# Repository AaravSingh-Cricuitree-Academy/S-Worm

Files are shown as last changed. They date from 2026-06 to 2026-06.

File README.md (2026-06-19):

# S-Worm
_Swarm based Watch operations for rescue missions_

Untitled design (16)

## Basic architechtural overview-
Essentially its a system of 2 different types of drones
1) The recon
2) The rescuer
   
And also

-> Ground station

Recon drone
-> The ground station uses TDMA architechture to direct ALL the drones.

-> This is intended to be used in situations of disaster like earthquakes, tsunamis, bombings ,and/or mapping out complex terrain. 

Both share the same flight controller and ESC board. The difference in them is speciality boards which are unique to the respective drone, defined below-

-> The recon's speciality board is equiped with a Camera and LIDAR which hovers over terrain to map it out and then stores it. After a full map out it sends the data to the ground station where the data is processed and the area is divided into zones and high risk areas.

-> The rescue is equipped with a Mic, GPR to, Thermal and regular camera all processed by a PI hat 2 to look for human signals even under debris.

Add a heading (1)

_Check [Hardware ReadMe](Hardware/Hardware_ReadMe.md) to have an in-depth
 overview of exactly what has been built ;)_

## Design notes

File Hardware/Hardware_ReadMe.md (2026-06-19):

# HARDWARE SPECS-



**Processing & Control**

    1 STM32F405RGT6 (Main Flight Controller MCU)- Brain of the system
    
    2 ADS112U04IPWR (Precision ADC)
  
**Navigation & Positioning**

    1) MAX-M10S-00B (GNSS/GPS Module) + U.FL connector
    
    2) BMP580 (Barometric Pressure Sensor)
    
    3) ICM-45686 (6-axis IMU)
    
    4) MMC5983MA (3-axis Magnetometer)
  
**Communications**

		1) E22-900M22S (900 MHz Telemetry/Radio Module) + U.Fl connector
		
**Power System**

	1) TPS2121RUXR (Power Multiplexer / Power Path Controller)
	2) TPS62130RGTR (Buck Converter)
	3) 2.2 µH Power Inductor
	
**Clock Sources**

	1) X322525MOB4SI- 25 MHz Crystal Oscillator
	2) Q13FC1350000400- 32.768 kHz Crystal (LSE)

**User Interface & Debug**

	1) USB-A Connector
	2) 3 × Status LEDs
	3) 2 × Tactile Push Buttons for reset and boot
	4) Test pads for major nets

**Passive Components**

	Decoupling capacitors (100 nF, 1 µF, 2.2 µF, 4.7 µF, 10 µF, 22 µF)
	Timing/load capacitors (6.8 pF, 20 pF)
	Filtering capacitors (3.3 nF, 10 nF)
	Resistor network (10 kΩ, 30 kΩ, 75 kΩ, 80 kΩ, 100 kΩ)
	FCM1608KF-601T03 (Ferrite Bead)

## Build reasoning
STM32F405 because i was drawing inspo from the existing speedybee f405 board

I ran out of ADCs in my STM32 so im reading the voltage given by my battery via a voltage divider and ADC to convert the analog voltage to UART so my STM32 can read it.

Cloclks, buttons, IMU, magnetometer and barometeric sensor were picked up from the guide

Power mux to allow seamless switch between USB power and battery power. 

E22-900M-2S because it has long range and I have worked with the module before

MAX-M10S-00B good features at a reasonable cost

Passive compnents were selected from the datasheet and/or the guide

Rest is rather self explainatory

## Schematic for quick reference



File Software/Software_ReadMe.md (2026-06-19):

# Software 
Yeah so this is just STM32cubeMX generated code nothing much to see here

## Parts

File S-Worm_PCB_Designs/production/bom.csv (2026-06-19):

Designator | Footprint | Quantity | Value | LCSC Part #
C10, C11, C12, C15, C20, C22, C26, C27, C32, C5, C6, C7 | 0402 | 12 | 100nF
C13, C9 | 0402 | 2 | 6.8pF
C14, C8 | 0402 | 2 | 20pF
C16 | 0402 | 1 | 1uF
C17, C18 | 0402 | 2 | 2.2uF
C19 | 0805 | 1 | 10uF
C2, C4 | 0402 | 2 | 4.7uF
C21, C30 | 0402 | 2 | 10uF
C23, C25, C31, C33 | 0402 | 4 | 0.1uF
C24 | 0402 | 1 | 3.3nF
C28 | 0402 | 1 | 10nF
C29 | 0402 | 1 | 22uf
D1, D2, D3 | 0805 | 3 | LED
J1 | USB_A_CNCTech_1001-011-01101_Horizontal | 1 | USB_A
J2, J3 | U.FL_Hirose_U.FL-R-SMT-1_Vertical | 2 | Conn_Coaxial
J4 | JST_ACH_BM03B-ACHSS-GAN-ETF_1x03-1MP_P1.20mm_Vertical | 1 | Conn_01x03_Pin
L1 | L0603 | 1 | FCM1608KF-601T03 | C141723
L2 | 0201 | 1 | 2.2 uH
R1, R2 | 0201 | 2 | 10k
R3 | 0402 | 1 | 75k
R4 | 0402 | 1 | 80k
R5 | 0402 | 1 | 30k
R6 | 0402 | 1 | 10k
R7, R8 | 0402 | 2 | 100k
SW1, SW2 | SW-SMD_L3.9-W3.0-P4.45 | 2 | TS-1088-AR02016 | C720477
TP1 | TestPoint_Pad_4.0x4.0mm | 1 | SP-_4
TP10 | TestPoint_Pad_4.0x4.0mm | 1 | 3.3v test pad
TP11 | TestPoint_Pad_4.0x4.0mm | 1 | GND test pad
TP2 | TestPoint_Pad_4.0x4.0mm | 1 | SP-_2
TP3 | TestPoint_Pad_4.0x4.0mm | 1 | SP-_3
TP4 | TestPoint_Pad_4.0x4.0mm | 1 | SP-_1
TP5 | TestPoint_Pad_4.0x4.0mm | 1 | SP+_4
TP6 | TestPoint_Pad_4.0x4.0mm | 1 | SP+_1
TP7 | TestPoint_Pad_4.0x4.0mm | 1 | SP+_3
TP8 | TestPoint_Pad_4.0x4.0mm | 1 | SP+_2
TP9 | TestPoint_Pad_4.0x4.0mm | 1 | Battery test pad
U1 | SMD-18_L10.1-W9.7-P1.10-TL_SKG09F | 1 | MAX-M10S-00B | C4153167
U2 | LQFP-64_L10.0-W10.0-P0.50-LS12.0-BL | 1 | STM32F405RGT6 | C15742
U3 | LGA-14_L3.0-W2.5-P0.50-TL | 1 | ICM-45686 | C22459454
U4 | LGA-16_L3.0-W3.0-P0.50-BL_SQ | 1 | MMC5983MA | C404329
U5 | VQFN-HR-12_L2.5-W2.0-P0.50-BL | 1 | TPS2121RUXR | C485916
U6 | QFN-16_L3.0-W3.0-P0.50-TL-EP1.7 | 1 | TPS62130RGTR | C43590
U7 | WIRELM-SMD_E22-900M22S | 1 | E22-900M22S | C411293
U8 | LGA-10_L2.0-W2.0-P0.50-TL_BMP580 | 1 | BMP580 | C22391138
U9 | TSSOP-16_L5.0-W4.4-P0.65-LS6.4-BL | 1 | ADS112U04IPWR | C701616
X1 | CRYSTAL-SMD_4P-L3.2-W2.5-BL | 1 | X322525MOB4SI | C9006
X2 | FC-135R_L3.2-W1.5 | 1 | Q13FC1350000400 | C32346

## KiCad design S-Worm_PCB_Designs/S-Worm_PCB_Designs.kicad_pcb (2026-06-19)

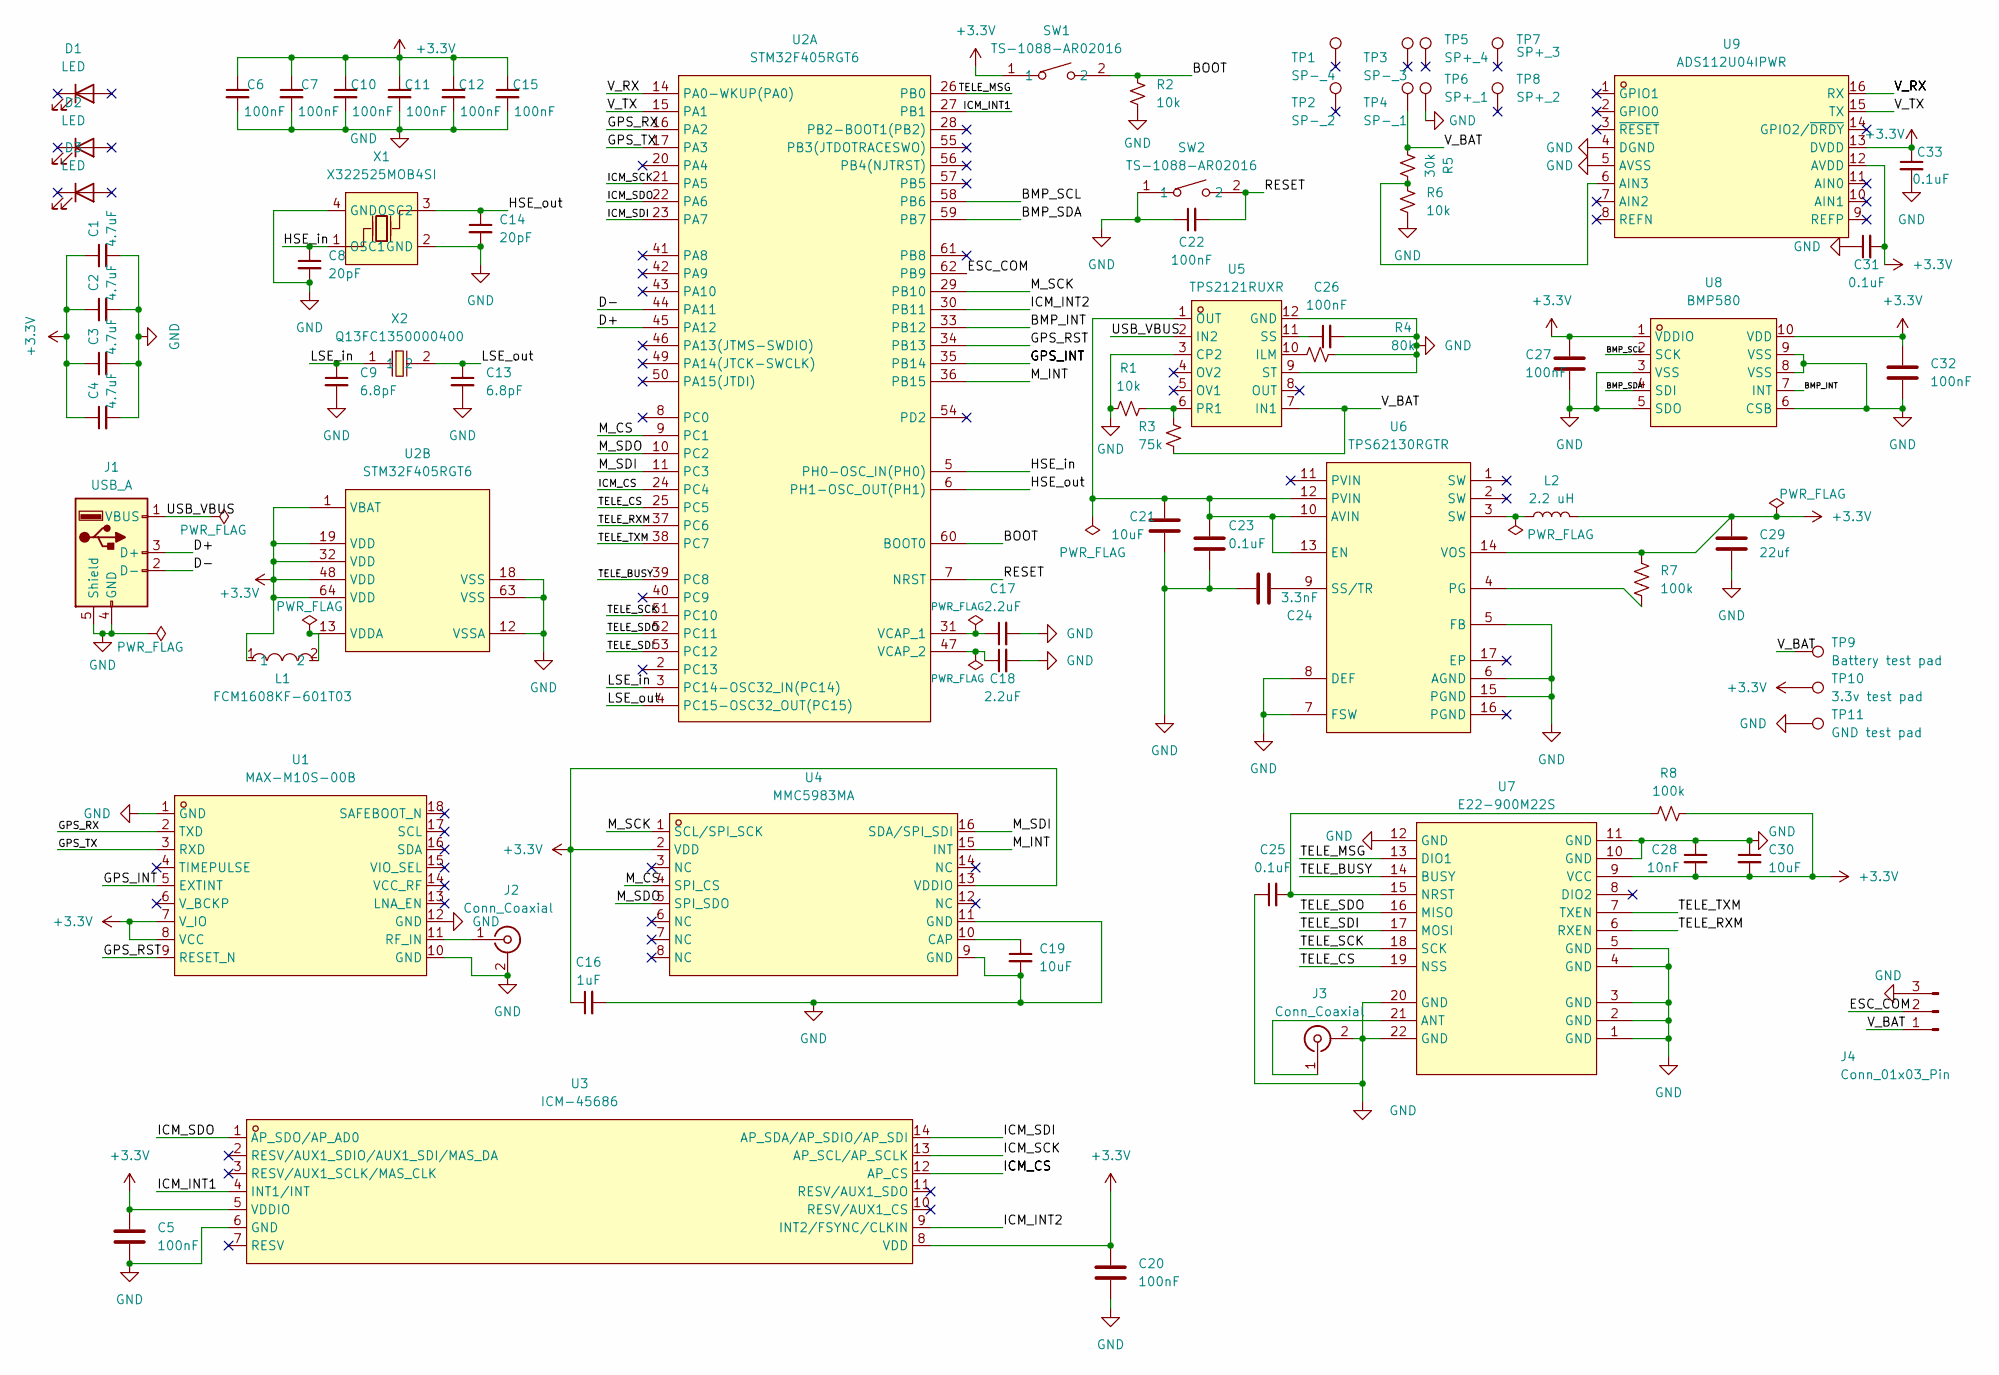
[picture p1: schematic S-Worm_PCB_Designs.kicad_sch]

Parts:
C1, C2, C3, C4: 4.7uF; C_0402_1005Metric
C5, C6, C7, C10, C11, C12, C15, C20, C22, C26, C27, C32: 100nF; C_0402_1005Metric
C8, C14: 20pF; C_0402_1005Metric
C9, C13: 6.8pF; C_0402_1005Metric
C16: 1uF; C_0402_1005Metric
C17, C18: 2.2uF; C_0402_1005Metric
C19: 10uF; C_0805_2012Metric
C21, C30: 10uF; C_0402_1005Metric
C23, C25, C31, C33: 0.1uF; C_0402_1005Metric
C24: 3.3nF; C_0402_1005Metric
C28: 10nF; C_0402_1005Metric
C29: 22uf; C_0402_1005Metric
D1, D2, D3: LED; LED_0805_2012Metric
J1: USB_A; USB_A_CNCTech_1001-011-01101_Horizontal
J2, J3: Conn_Coaxial; U.FL_Hirose_U.FL-R-SMT-1_Vertical
J4: Conn_01x03_Pin; JST_ACH_BM03B-ACHSS-GAN-ETF_1x03-1MP_P1.20mm_Vertical
L1: FCM1608KF-601T03; L0603; MPN FCM1608KF-601T03; LCSC Part C141723
L2: 2.2 uH; L_0201_0603Metric
R1, R2: 10k; R_0201_0603Metric
R3: 75k; R_0402_1005Metric
R4: 80k; R_0402_1005Metric
R5: 30k; R_0402_1005Metric
R6: 10k; R_0402_1005Metric
R7, R8: 100k; R_0402_1005Metric
SW1, SW2: TS-1088-AR02016; SW-SMD_L3.9-W3.0-P4.45; MPN TS-1088-AR02016; LCSC Part C720477
TP1: SP-_4; TestPoint_Pad_4.0x4.0mm
TP2: SP-_2; TestPoint_Pad_4.0x4.0mm
TP3: SP-_3; TestPoint_Pad_4.0x4.0mm
TP4: SP-_1; TestPoint_Pad_4.0x4.0mm
TP5: SP+_4; TestPoint_Pad_4.0x4.0mm
TP6: SP+_1; TestPoint_Pad_4.0x4.0mm
TP7: SP+_3; TestPoint_Pad_4.0x4.0mm
TP8: SP+_2; TestPoint_Pad_4.0x4.0mm
TP9: Battery test pad; TestPoint_Pad_4.0x4.0mm
TP10: 3.3v test pad; TestPoint_Pad_4.0x4.0mm
TP11: GND test pad; TestPoint_Pad_4.0x4.0mm
U1: MAX-M10S-00B; SMD-18_L10.1-W9.7-P1.10-TL_SKG09F; MPN MAX-M10S-00B; LCSC Part C4153167
U2: STM32F405RGT6; LQFP-64_L10.0-W10.0-P0.50-LS12.0-BL; MPN STM32F405RGT6; LCSC Part C15742
U3: ICM-45686; LGA-14_L3.0-W2.5-P0.50-TL; MPN ICM-45686; LCSC Part C22459454
U4: MMC5983MA; LGA-16_L3.0-W3.0-P0.50-BL_SQ; MPN MMC5983MA; LCSC Part C404329
U5: TPS2121RUXR; VQFN-HR-12_L2.5-W2.0-P0.50-BL; MPN TPS2121RUXR; LCSC Part C485916
U6: TPS62130RGTR; QFN-16_L3.0-W3.0-P0.50-TL-EP1.7; MPN TPS62130RGTR; LCSC Part C43590
U7: E22-900M22S; WIRELM-SMD_E22-900M22S; MPN E22-900M22S; LCSC Part C411293
U8: BMP580; LGA-10_L2.0-W2.0-P0.50-TL_BMP580; MPN BMP580; LCSC Part C22391138
U9: ADS112U04IPWR; TSSOP-16_L5.0-W4.4-P0.65-LS6.4-BL; MPN ADS112U04IPWR; LCSC Part C701616
X1: X322525MOB4SI; CRYSTAL-SMD_4P-L3.2-W2.5-BL; MPN X322525MOB4SI; LCSC Part C9006
X2: Q13FC1350000400; FC-135R_L3.2-W1.5; MPN Q13FC13500004; LCSC Part C32346

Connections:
+3.3V: C1.1, C2.1, C3.1, C4.1, C5.1, C6.1, C7.1, C10.1, C11.1, C12.1, C15.1, C16.1, C20.1, C27.1, C28.2, C29.1, C30.2, C31.2, C32.1, C33.1, L1.1, L2.2, R7.1, R8.2, SW1.1, TP10.1, U1.7 (V_IO), U1.8 (VCC), U2.1 (VBAT), U2.19 (VDD), U2.32 (VDD), U2.48 (VDD), U2.64 (VDD), U3.5 (VDDIO), U3.8 (VDD), U4.2 (VDD), U4.13 (VDDIO), U6.14 (VOS), U7.9 (VCC), U8.1 (VDDIO), U8.10 (VDD), U9.12 (AVDD), U9.13 (DVDD)
/BMP_INT: U2.33 (PB12), U8.7 (INT)
/BMP_SCL: U2.58 (PB6), U8.2 (SCK)
/BMP_SDA: U2.59 (PB7), U8.4 (SDI)
/BOOT: R2.1, SW1.2, U2.60 (BOOT0)
/D+: J1.3 (D+), U2.45 (PA12)
/D-: J1.2 (D-), U2.44 (PA11)
/ESC_COM: J4.2, U2.62 (PB9)
/GPS_INT: U1.5 (EXTINT), U2.35 (PB14)
/GPS_RST: U1.9 (RESET_N), U2.34 (PB13)
/GPS_RX: U1.2 (TXD), U2.16 (PA2)
/GPS_TX: U1.3 (RXD), U2.17 (PA3)
/HSE_in: C8.1, U2.5 (PH0-OSC_IN(PH0)), X1.1 (OSC1)
/HSE_out: C14.1, U2.6 (PH1-OSC_OUT(PH1)), X1.3 (OSC2)
/ICM_CS: U2.24 (PC4), U3.12 (AP_CS)
/ICM_INT1: U2.27 (PB1), U3.4 (INT1/INT)
/ICM_INT2: U2.30 (PB11), U3.9 (INT2/FSYNC/CLKIN)
/ICM_SCK: U2.21 (PA5), U3.13 (AP_SCL/AP_SCLK)
/ICM_SDI: U2.23 (PA7), U3.14 (AP_SDA/AP_SDIO/AP_SDI)
/ICM_SDO: U2.22 (PA6), U3.1 (AP_SDO/AP_AD0)
/LSE_in: C9.1, U2.3 (PC14-OSC32_IN(PC14)), X2.1
/LSE_out: C13.1, U2.4 (PC15-OSC32_OUT(PC15)), X2.2
/M_CS: U2.9 (PC1), U4.4 (SPI_CS)
/M_INT: U2.36 (PB15), U4.15 (INT)
/M_SCK: U2.29 (PB10), U4.1 (SCL/SPI_SCK)
/M_SDI: U2.11 (PC3), U4.16 (SDA/SPI_SDI)
/M_SDO: U2.10 (PC2), U4.5 (SPI_SDO)
/RESET: C22.2, SW2.2, U2.7 (NRST)
/TELE_BUSY: U2.39 (PC8), U7.14 (BUSY)
/TELE_CS: U2.25 (PC5), U7.19 (NSS)
/TELE_MSG: U2.26 (PB0), U7.13 (DIO1)
/TELE_RXM: U2.37 (PC6), U7.6 (RXEN)
/TELE_SCK: U2.51 (PC10), U7.18 (SCK)
/TELE_SDI: U2.53 (PC12), U7.17 (MOSI)
/TELE_SDO: U2.52 (PC11), U7.16 (MISO)
/TELE_TXM: U2.38 (PC7), U7.7 (TXEN)
/USB_VBUS: J1.1 (VBUS), U5.2 (IN2)
/V_BAT: J4.1, R3.2, R5.1, TP4.1, TP9.1, U5.7 (IN1)
/V_RX: U2.14 (PA0-WKUP(PA0)), U9.16 (RX)
/V_TX: U2.15 (PA1), U9.15 (TX)
GND: C1.2, C2.2, C3.2, C4.2, C5.2, C6.2, C7.2, C8.2, C9.2, C10.2, C11.2, C12.2, C13.2, C14.2, C15.2, C16.2, C17.2, C18.2, C19.2, C20.2, C21.2, C22.1, C23.2, C24.2, C25.1, C26.2, C27.2, C28.1, C29.2, C30.1, C31.1, C32.2, C33.2, J1.4 (GND), J1.5 (Shield), J2.2 (Ext), J3.2 (Ext), J4.3, J4.MP, R1.1, R2.2, R4.2, R6.2, SW2.1, TP6.1, TP11.1, U1.1 (GND), U1.10 (GND), U1.12 (GND), U2.12 (VSSA), U2.18 (VSS), U2.63 (VSS), U3.6 (GND), U4.9 (GND), U4.11 (GND), U5.3 (CP2), U5.9 (ST), U5.12 (GND), U6.5 (FB), U6.6 (AGND), U6.7 (FSW), U6.8 (DEF), U6.15 (PGND), U7.1 (GND), U7.2 (GND), U7.3 (GND), U7.4 (GND), U7.5 (GND), U7.10 (GND), U7.11 (GND), U7.12 (GND), U7.20 (GND), U7.22 (GND), U8.3 (VSS), U8.5 (SDO), U8.6 (CSB), U8.8 (VSS), U8.9 (VSS), U9.4 (DGND), U9.5 (AVSS), X1.2 (GND), X1.4 (GND)
unnamed: J2.1 (In), U1.11 (RF_IN)
unnamed: J3.1 (In), U7.21 (ANT)
unnamed: L2.1, U6.3 (SW)
unnamed: C17.1, U2.31 (VCAP_1)
unnamed: C18.1, U2.47 (VCAP_2)
unnamed: L1.2, U2.13 (VDDA)
unnamed: C19.1, U4.10 (CAP)
unnamed: R4.1, U5.10 (ILM)
unnamed: R1.2, R3.1, U5.6 (PR1)
unnamed: C26.1, U5.11 (SS)
unnamed: C21.1, C23.1, U5.1 (OUT), U6.10 (AVIN), U6.12 (PVIN), U6.13 (EN)
unnamed: R7.2, U6.4 (PG)
unnamed: C24.1, U6.9 (SS/TR)
unnamed: C25.2, R8.1, U7.15 (NRST)
unnamed: R5.2, R6.1, U9.6 (AIN3)

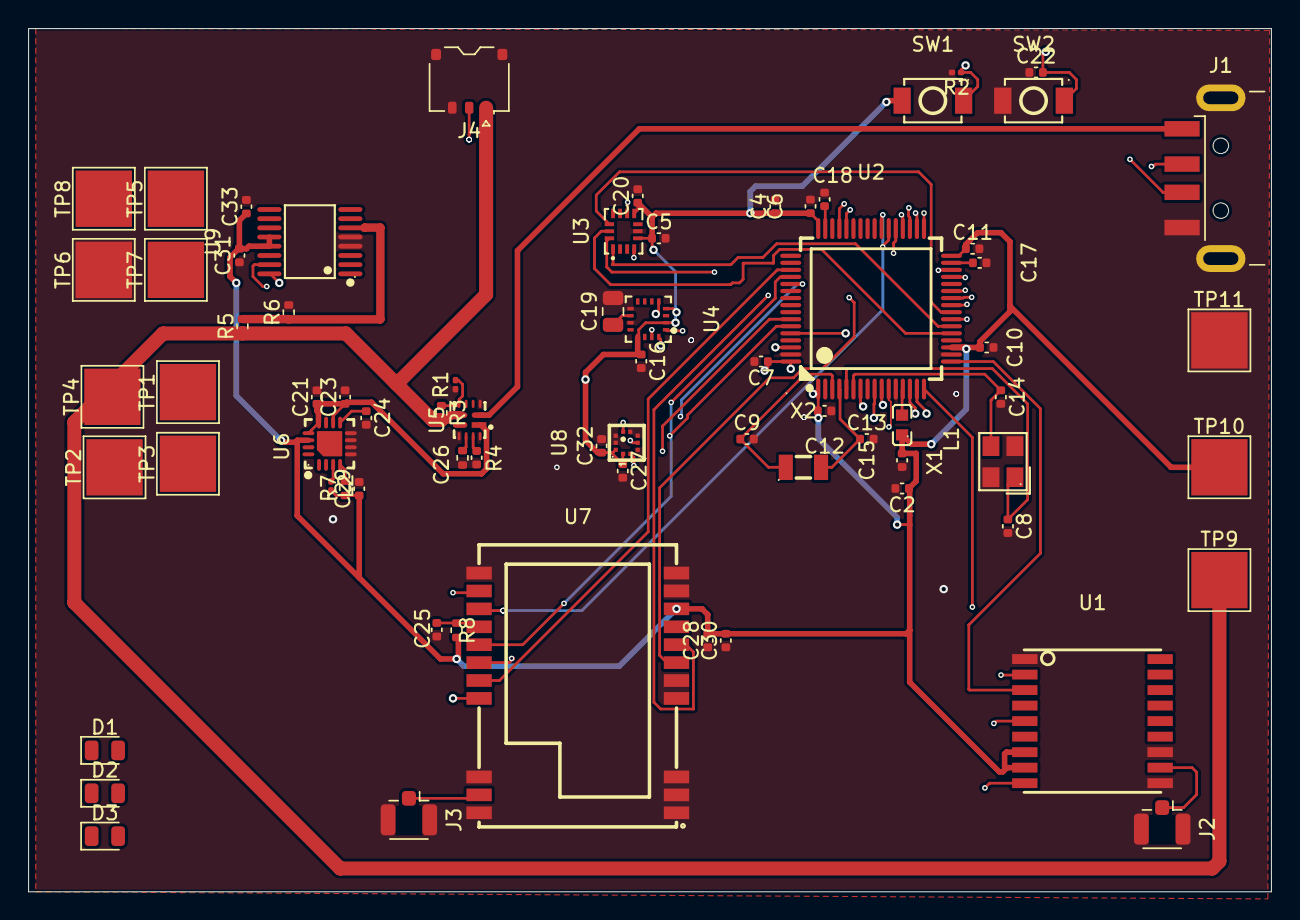
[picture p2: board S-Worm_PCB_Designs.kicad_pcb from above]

Board: 4 copper layers, 88.1 x 61.2 mm, 72 parts (0 on the bottom side), 56 nets.

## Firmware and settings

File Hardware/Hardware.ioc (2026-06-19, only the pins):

Mcu.UserName=STM32F405RGTx
PA0-WKUP.GPIO_Label=V_TX
PA0-WKUP.Signal=UART4_TX
PA1.GPIO_Label=V_RX
PA1.Signal=UART4_RX
PA11.Signal=USB_OTG_FS_DM
PA12.Signal=USB_OTG_FS_DP
PA2.GPIO_Label=GPS_TX
PA2.Signal=USART2_TX
PA3.GPIO_Label=GPS_RX
PA3.Signal=USART2_RX
PA5.GPIO_Label=IMU_SCK
PA5.Signal=SPI1_SCK
PA6.GPIO_Label=IMU_SDO
PA6.Signal=SPI1_MISO
PA7.GPIO_Label=IMU_SDI
PA7.Signal=SPI1_MOSI
PA9.GPIO_Label=ESC_COM
PA9.Signal=USART1_TX
PB0.GPIO_Label=TELE_MSG
PB0.Signal=GPIO_Output
PB1.GPIO_Label=IMU_INT1
PB1.Signal=GPXTI1
PB10.GPIO_Label=M_SCK
PB10.Signal=SPI2_SCK
PB11.GPIO_Label=IMU_INT2
PB11.Signal=GPXTI11
PB12.GPIO_Label=BMP_INT
PB12.Signal=GPXTI12
PB13.GPIO_Label=GPS_RST
PB13.Signal=GPIO_Output
PB14.GPIO_Label=GPS_INT
PB14.Signal=GPXTI14
PB15.GPIO_Label=M_INT
PB15.Signal=GPXTI15
PB5.Signal=I2C1_SMBA
PB6.GPIO_Label=BMP_SCL
PB6.Signal=I2C1_SCL
PB7.GPIO_Label=BMP_SDA
PB7.Signal=I2C1_SDA
PC1.GPIO_Label=M_CS
PC1.Signal=GPIO_Output
PC10.GPIO_Label=TELE_SCK
PC10.Signal=SPI3_SCK
PC11.GPIO_Label=TELE_SDO
PC11.Signal=SPI3_MISO
PC12.GPIO_Label=TELE_SDI
PC12.Signal=SPI3_MOSI
PC14-OSC32_IN.GPIO_Label=LSE_IN
PC14-OSC32_IN.Signal=RCC_OSC32_IN
PC15-OSC32_OUT.GPIO_Label=LSE_OUT
PC15-OSC32_OUT.Signal=RCC_OSC32_OUT
PC2.GPIO_Label=M_SDO
PC2.Signal=SPI2_MISO
PC3.GPIO_Label=M_SDI
PC3.Signal=SPI2_MOSI
PC4.GPIO_Label=IMU_CS
PC4.Signal=GPIO_Output
PC5.GPIO_Label=TELE_CS
PC5.Signal=GPIO_Output
PC6.GPIO_Label=TELE_RXM
PC6.Signal=GPIO_Output
PC7.GPIO_Label=TELE_TXM
PC7.Signal=GPIO_Output
PC8.GPIO_Label=TELE_BUSY
PC8.Signal=GPIO_Input
PH0-OSC_IN.GPIO_Label=HSE_IN
PH0-OSC_IN.Signal=RCC_OSC_IN
PH1-OSC_OUT.GPIO_Label=HSE_OUT
PH1-OSC_OUT.Signal=RCC_OSC_OUT

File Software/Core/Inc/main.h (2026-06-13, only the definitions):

#define LSE_IN_Pin GPIO_PIN_14
#define LSE_IN_GPIO_Port GPIOC
#define LSE_OUT_Pin GPIO_PIN_15
#define LSE_OUT_GPIO_Port GPIOC
#define HSE_IN_Pin GPIO_PIN_0
#define HSE_IN_GPIO_Port GPIOH
#define HSE_OUT_Pin GPIO_PIN_1
#define HSE_OUT_GPIO_Port GPIOH
#define M_CS_Pin GPIO_PIN_1
#define M_CS_GPIO_Port GPIOC
#define M_SDO_Pin GPIO_PIN_2
#define M_SDO_GPIO_Port GPIOC
#define M_SDI_Pin GPIO_PIN_3
#define M_SDI_GPIO_Port GPIOC
#define V_TX_Pin GPIO_PIN_0
#define V_TX_GPIO_Port GPIOA
#define V_RX_Pin GPIO_PIN_1
#define V_RX_GPIO_Port GPIOA
#define GPS_TX_Pin GPIO_PIN_2
#define GPS_TX_GPIO_Port GPIOA
#define GPS_RX_Pin GPIO_PIN_3
#define GPS_RX_GPIO_Port GPIOA
#define IMU_SCK_Pin GPIO_PIN_5
#define IMU_SCK_GPIO_Port GPIOA
#define IMU_SDO_Pin GPIO_PIN_6
#define IMU_SDO_GPIO_Port GPIOA
#define IMU_SDI_Pin GPIO_PIN_7
#define IMU_SDI_GPIO_Port GPIOA
#define IMU_CS_Pin GPIO_PIN_4
#define IMU_CS_GPIO_Port GPIOC
#define TELE_CS_Pin GPIO_PIN_5
#define TELE_CS_GPIO_Port GPIOC
#define TELE_MSG_Pin GPIO_PIN_0
#define TELE_MSG_GPIO_Port GPIOB
#define IMU_INT1_Pin GPIO_PIN_1
#define IMU_INT1_GPIO_Port GPIOB
#define M_SCK_Pin GPIO_PIN_10
#define M_SCK_GPIO_Port GPIOB
#define IMU_INT2_Pin GPIO_PIN_11
#define IMU_INT2_GPIO_Port GPIOB
#define BMP_INT_Pin GPIO_PIN_12
#define BMP_INT_GPIO_Port GPIOB
#define GPS_RST_Pin GPIO_PIN_13
#define GPS_RST_GPIO_Port GPIOB
#define GPS_INT_Pin GPIO_PIN_14
#define GPS_INT_GPIO_Port GPIOB
#define M_INT_Pin GPIO_PIN_15
#define M_INT_GPIO_Port GPIOB
#define TELE_RXM_Pin GPIO_PIN_6
#define TELE_RXM_GPIO_Port GPIOC
#define TELE_TXM_Pin GPIO_PIN_7
#define TELE_TXM_GPIO_Port GPIOC
#define TELE_BUSY_Pin GPIO_PIN_8
#define TELE_BUSY_GPIO_Port GPIOC
#define TELE_SCK_Pin GPIO_PIN_10
#define TELE_SCK_GPIO_Port GPIOC
#define TELE_SDO_Pin GPIO_PIN_11
#define TELE_SDO_GPIO_Port GPIOC
#define TELE_SDI_Pin GPIO_PIN_12
#define TELE_SDI_GPIO_Port GPIOC
#define BMP_SCL_Pin GPIO_PIN_6
#define BMP_SCL_GPIO_Port GPIOB
#define BMP_SDA_Pin GPIO_PIN_7
#define BMP_SDA_GPIO_Port GPIOB

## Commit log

2026-06-10 switching the module lol
    [S-Worm_PCB_Designs.kicad_sch]
2026-06-12 it didnt commite yesterday i dunno why
    [S-Worm_PCB_Designs.kicad_sch]
2026-06-12 adc wow
2026-06-12 adc aaa
    [S-Worm_PCB_Designs.kicad_sch]
2026-06-15 i dunno
    [S-Worm_PCB_Designs.kicad_sch]
2026-06-19 almost there
    [S-Worm_PCB_Designs.kicad_pcb, S-Worm_PCB_Designs.kicad_sch, bom.csv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]

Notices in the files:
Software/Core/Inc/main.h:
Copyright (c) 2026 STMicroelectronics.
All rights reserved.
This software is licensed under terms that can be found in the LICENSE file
